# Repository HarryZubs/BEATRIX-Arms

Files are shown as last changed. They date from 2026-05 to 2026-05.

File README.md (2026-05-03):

This Repo contains all of the required software and hardware to create an Open-Source BEATRIX Robot Arm.

# Hardware 

printFiles contains all of the STL files that are required to be 3D printed for the full robot arm. All prints are required to be 30% infill PLA.
BOM contains all of the parts required to be purchased to complete the robot arm.
buildGuide contains a guide to the assembly of the arm.
schem contains an Altium Designer Schematic file defining the electrical connections for the full system.

# Software

Contains all of the software required to control the arm.

## WSL contains all of the ROS software

This was all ran inside WSL2 in an Ubuntu 20.04 envionment using ros-noetic.
Any ros-noetic build should be functional however Ubuntu 20.04 is reccommended. 
All essnetial packages are required: python3-rosdep python3-rosinstall python3-rosinstall-generator python3-wstool build-essential
Additionall ros-pinocchio is required: https://github.com/stack-of-tasks/pinocchio.git

To run the robot arm all of the ros nodes must be running simultaneously in a enviornment which is communcaiting over TCP with the GUI.

## WindowsGUI contains the GUI and communcation software

This is not unique to windows but was developed for a windows envionrment.
The required python packages are: pyserial and coppeliasim_zmqremoteapi_client.
Inside the code the COM port for the ardunio and the address for the communcation with the ROS software must be configured.

## Arduino contains the motor control software

This code must be flashed onto an ardunio. Any ardunio nano should function however it has only been tested with an ardunio nano rev2.
This requires the following package: Adafruit_PWMServoDriver

## Simulator contains the CoppeliaSim model

The file can be opened inside v4.10.0 and can then communciate and be controlled by the rest of the software.

# Testing contains all of the scripts used during development and testing of the arm

IMU Res contains the ardunio, python code and results of measuring the repeatability with the IMU.
Dynamic test evalutes the workspace of the arm under dyanmic conditions
Kinematic eval evlautes the kinematic workspace of the arm when compared to other humanoid kinematic chains
Motion eval evalutes the similarity betwwen motion of the robot arm and a human arm
Payload eval evaluates the reduction in workspace in loaded conditions
Pose gen generates random reachable poses
Rand pose is a ROS node that will communicate with the ROS software to instruct a move to a randomly reachable pose
Rand traj s a ROS node that will communicate with the ROS software to instruct randomly generated trajectory
Traj eval graphs the trajectory for a random pose

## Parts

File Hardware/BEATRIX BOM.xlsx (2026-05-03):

Ordered 04/03/26 by Harry | Stepper UK | Part | Quantity | Cost | Total | Link
 |  | J1/J2 Motor | 2 | £32.69 | £65.38 | https://www.stepperonline.co.uk/nema-17-stepper-motor-bipolar-l-48mm-w-gear-ratio-14-1-planetary-gearbox-17hs19-1684s-pg14.html
 |  | J3 Motor | 1 | £23.79 | £23.79 | https://www.stepperonline.co.uk/nema-17-stepper-motor-l-39mm-gear-ratio-10-1-mg-series-planetary-gearbox-17hs15-1584s-mg10.html
 |  | J4/J5/J6/J7 Motor | 1 | £22.67 | £22.67 | https://www.stepperonline.co.uk/5pcs-e-series-nema-17-bipolar-42ncm-59-49oz-in-1-5a-42x42x38mm-4-wires-w-1m-cable-connector-5-17he15-1504s.html
 |  | Delivery |  |  | £9.40
 |  | Total |  |  | £121.24
 | Simply Bearings | Part | Quantity | Cost | Total | Link
 |  | J1 / J3 Bearings | 4 | £5.98 | £23.92 | https://simplybearings.co.uk/shop/p2146031/ZEN-618082RS-Rubber-Sealed-Deep-Groove-Ball-Bearing-40x52x7mm-Allow-2-3-Days/product_info.html
 |  | J2/J4/J6 Bearings | 6 | £3.98 | £23.88 | https://simplybearings.co.uk/shop/p170503/161012RS-Budget-Rubber-Sealed-Deep-Groove-Ball-Bearing-12x30x8mm/product_info.html
 |  | J5 Bearings | 2 | £4.27 | £8.54 | https://simplybearings.co.uk/shop/p2146128/ZEN-619052RS-Rubber-Sealed-Deep-Groove-Ball-Bearing-25x42x9mm-Allow-2-3-Days/product_info.html
 |  | J1 / J3 Circlip | 2 | £3.75 | £7.50 | https://simplybearings.co.uk/shop/p82858/External-Circlip-for-40mm-Shaft-Diameter-Un-Sprung-Diameter-36.5mm/product_info.html
 |  | J5 Circlip | 1 | £3.27 | £3.27 | https://simplybearings.co.uk/shop/p82843/External-Circlip-for-25mm-Shaft-Diameter-Un-Sprung-Diameter-23.2mm/product_info.html
 |  | VAT |  |  | £13.42
 |  | Total |  |  | £80.53
 | RS | Part | Quantity | Cost | Total | Link
 |  | J2/J4/J6 Circlip | 1 | £2.60 | £2.60 | https://uk.rs-online.com/web/p/circlips/0289247
 |  | M3 Inserts | 1 | £9.29 | £9.29 | https://uk.rs-online.com/web/p/threaded-inserts/0278534
 |  | M3 Bolts | 1 | £6.23 | £6.23 | https://uk.rs-online.com/web/p/machine-screws/9141771
 |  | M6 Bolts | 1 | £11.16 | £11.16 | https://uk.rs-online.com/web/p/socket-screws/8229127
 |  | M6 Nuts | 1 | £5.25 | £5.25 | https://uk.rs-online.com/web/p/hex-nuts/0525919
 |  | VAT |  |  | £6.91
 |  | Total |  |  | £41.44
 |  | Total |  |  | £243.21
To be ordered by Uriel | Amazon | Part | Quantity | Cost | Total | Link
 |  | J2/J4/J6 Driven Pulley | 3 | £6.19 | £18.57 | https://www.amazon.co.uk/sourcing-map-Synchronous-Aluminum-Printer/dp/B0DNFCVW62
 |  | J2 Drive Pulley | 1 | £8.98 | £8.98 | https://www.amazon.co.uk/Super-Pulley-Aluminum-Timing-Printer/dp/B0CND54G7W?s=industrial
 |  | J4/J6 Drive Pulley | 1 | £8.98 | £8.98 | https://www.amazon.co.uk/Super-Pulley-Aluminum-Timing-Printer/dp/B0CND58QZJ?s=industrial
 |  | J2/J4/J6 Belt | 3 | £7.39 | £22.17 | https://www.amazon.co.uk/Closed-Loop-Timing-Synchronous-Printer-Accessories/dp/B0B2W9V3N6?s=industrial
 |  | J2/J4/J6 Idlier | 1 | £11.98 | £11.98 | https://www.amazon.co.uk/Super-Pulley-Aluminum-Timing-Printer/dp/B0F82V92D9?s=industrial
 |  | Delivery |  |  | £0.00
 |  | Total |  |  | £70.68
Ask technicians for | Pi Hut | Part | Quantity | Cost | Total | Link
 |  | Stepper Motor Driver | 7 | £3.50 | £24.50 | https://thepihut.com/products/l298n-motor-stepper-driver
 |  | Delivery |  |  | £3.50
 |  | Total |  |  | £28.00

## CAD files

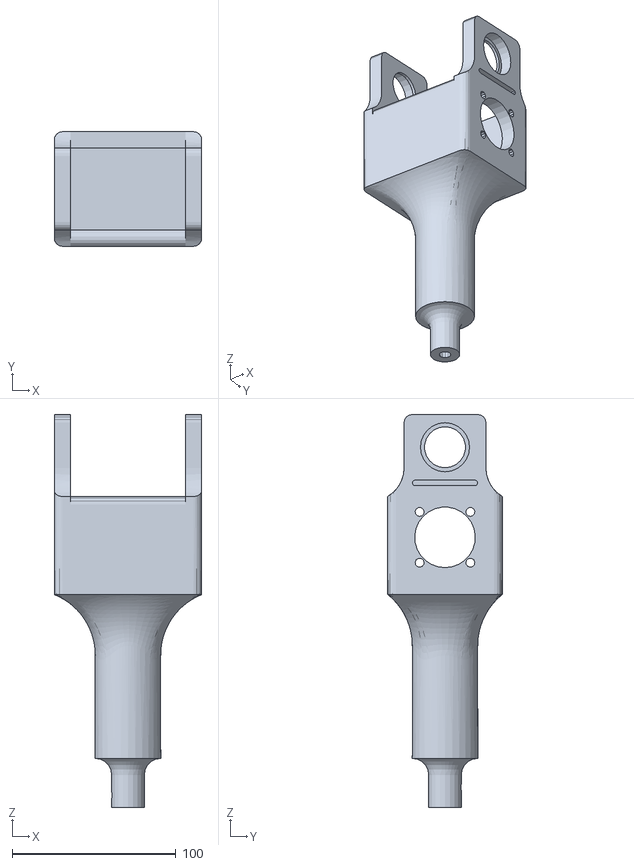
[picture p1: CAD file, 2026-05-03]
Hardware/PrintFiles/J1_Main.stl
90.0 x 70.0 x 240.0

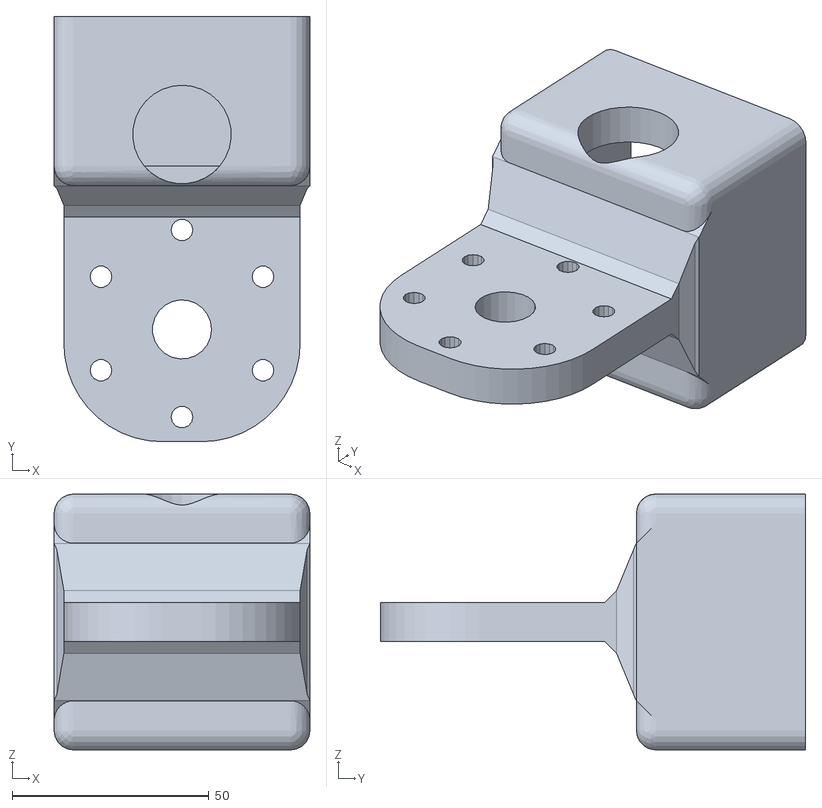
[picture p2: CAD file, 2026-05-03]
Hardware/PrintFiles/J4_Main.stl
65.0 x 108.0 x 65.0

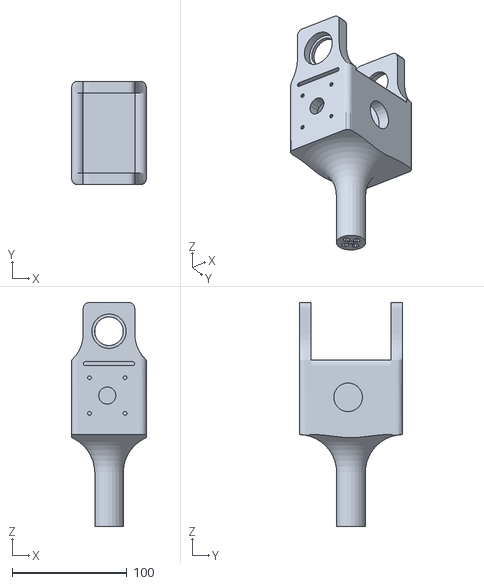
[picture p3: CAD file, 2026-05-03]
Hardware/PrintFiles/J5_Main.stl
65.0 x 90.0 x 195.0

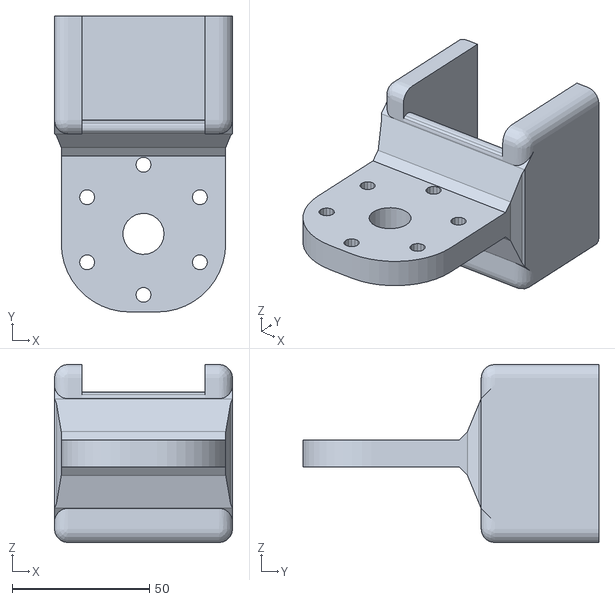
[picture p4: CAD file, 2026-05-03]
Hardware/PrintFiles/L2_main.stl
65.0 x 108.0 x 65.0

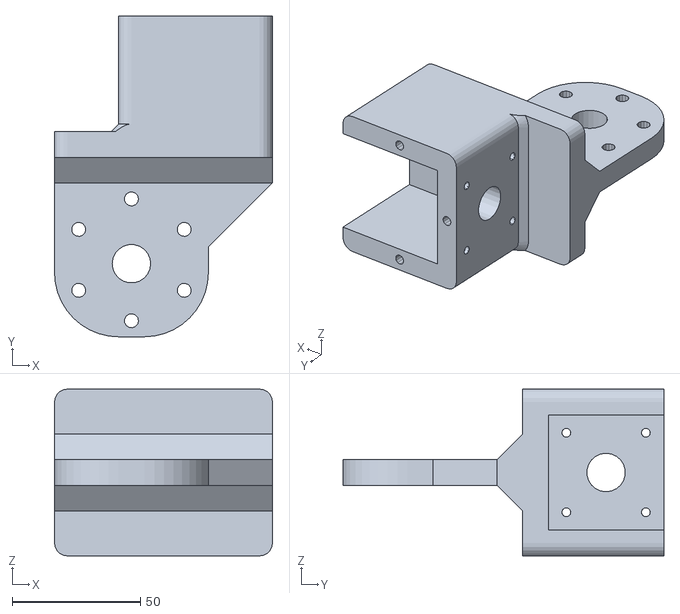
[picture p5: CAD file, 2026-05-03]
Hardware/PrintFiles/L6_main.stl
85.0 x 125.0 x 65.0

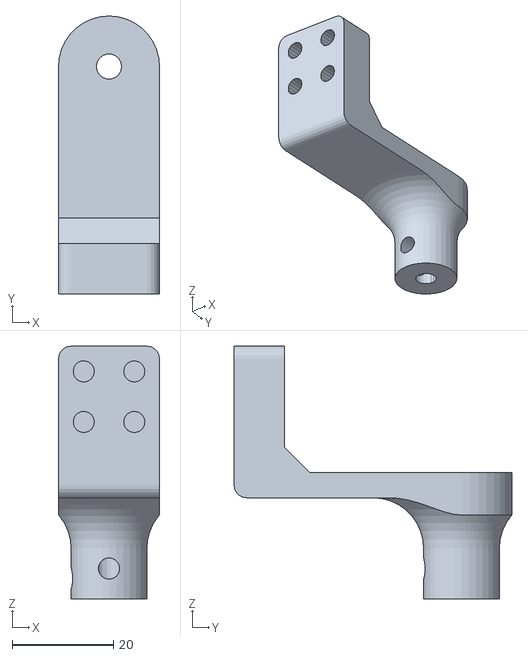
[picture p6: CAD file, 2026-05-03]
Hardware/PrintFiles/J7_Main.stl
20.0 x 55.0 x 50.0

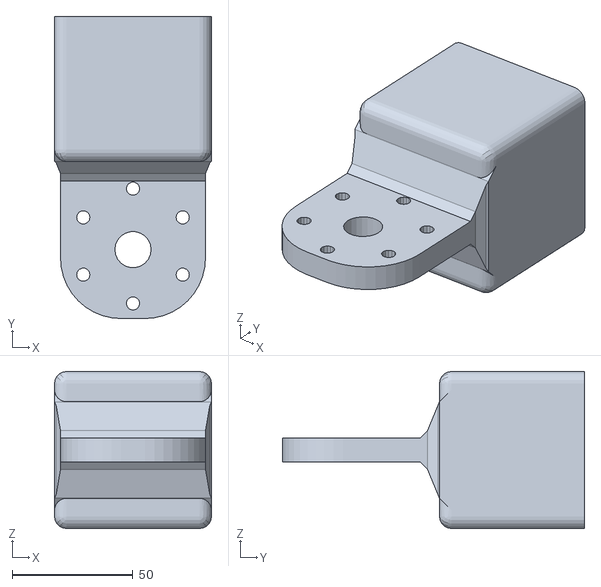
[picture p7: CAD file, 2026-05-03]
Hardware/PrintFiles/J2_Main.stl
65.0 x 125.0 x 65.0

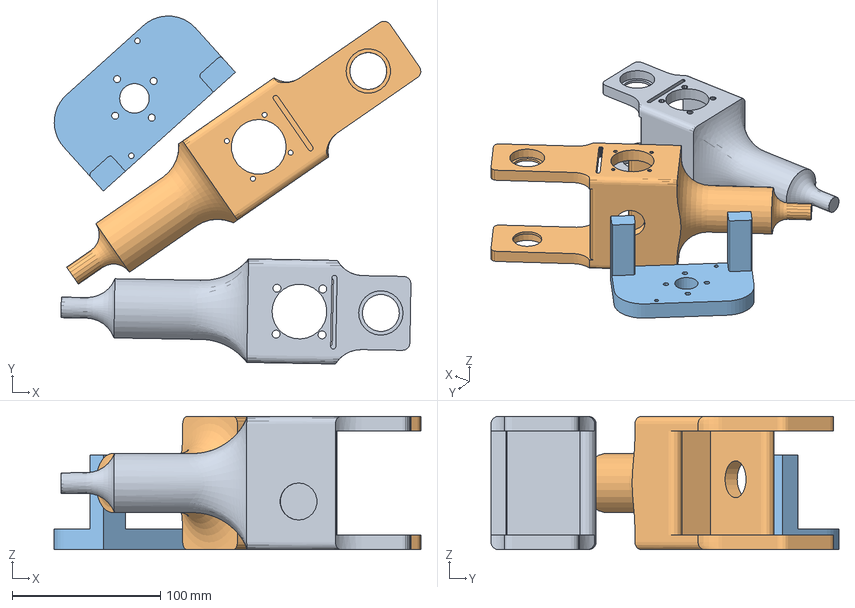
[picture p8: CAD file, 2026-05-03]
Hardware/PrintFiles/L1_Main.3mf
247.6 x 235.1 x 90.0 mm
L1_Main.stl
L3_Main.stl
L1_MountingPlate_3_Real.stl

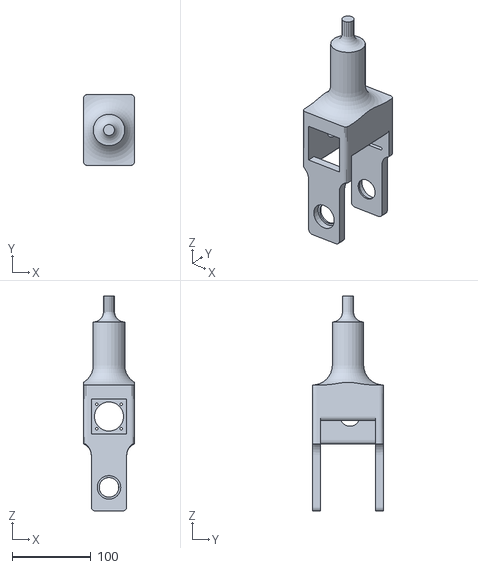
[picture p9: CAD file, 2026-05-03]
Hardware/PrintFiles/L3_Main.stl
65.0 x 90.0 x 273.0

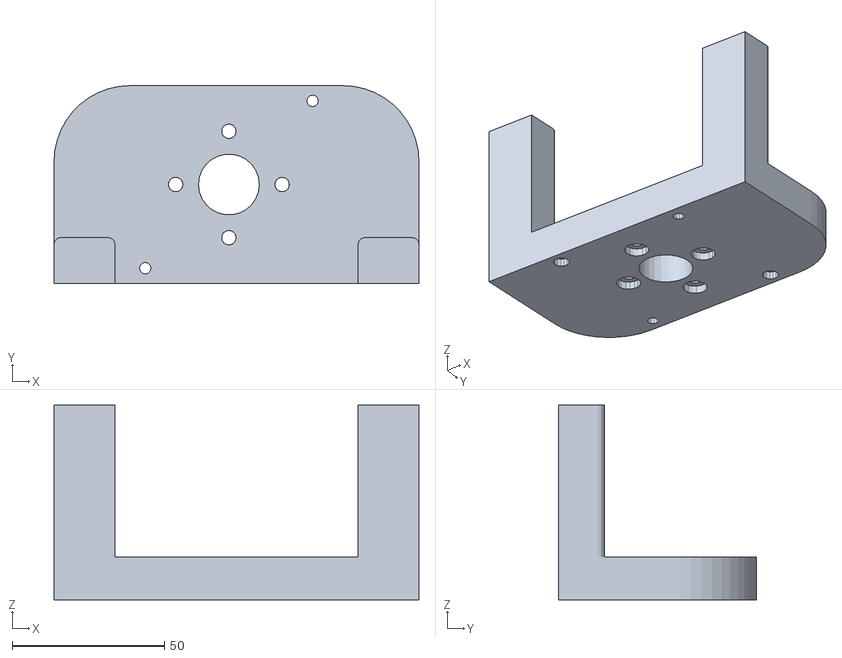
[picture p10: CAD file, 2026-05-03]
Hardware/PrintFiles/L1_MountingPlate_3_Real.stl
120.0 x 65.0 x 64.0

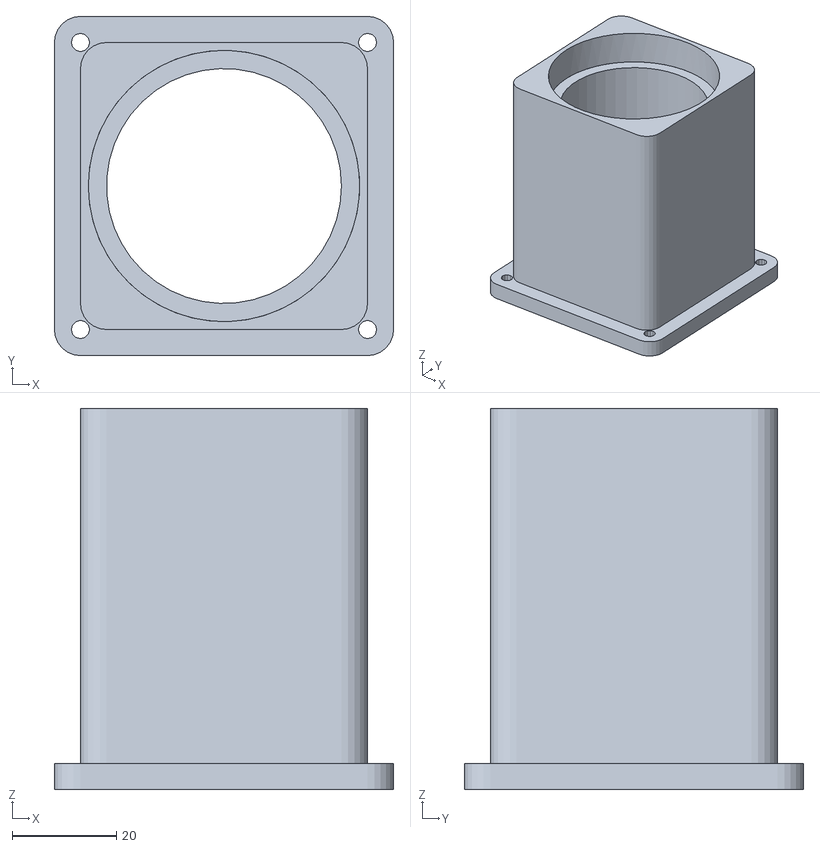
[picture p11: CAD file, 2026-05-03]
Hardware/PrintFiles/L1_BearingHousing.stl
65.0 x 65.0 x 73.0

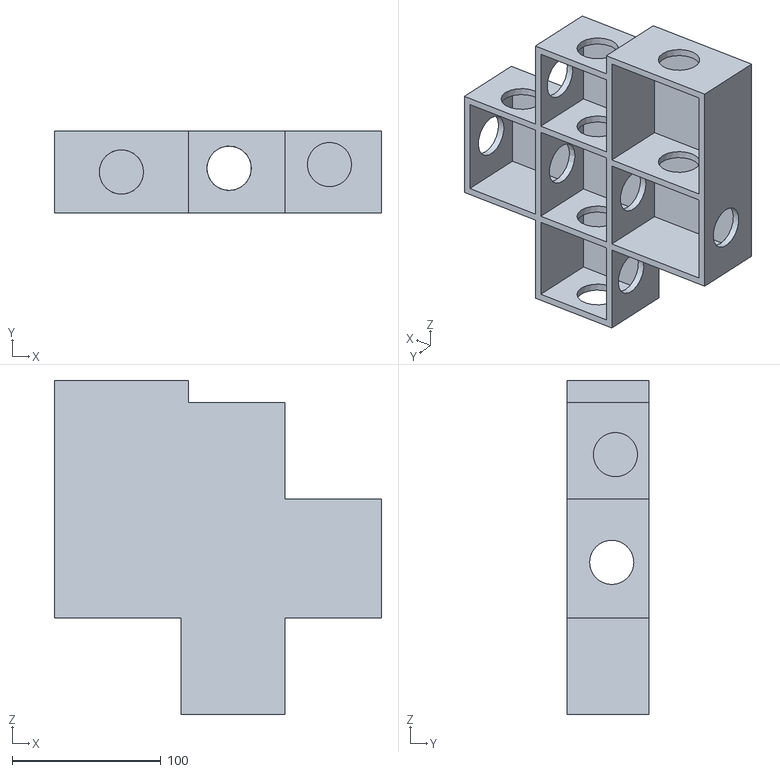
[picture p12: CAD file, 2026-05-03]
Hardware/PrintFiles/ElectronicsBox2.stl
220.0 x 55.0 x 225.0

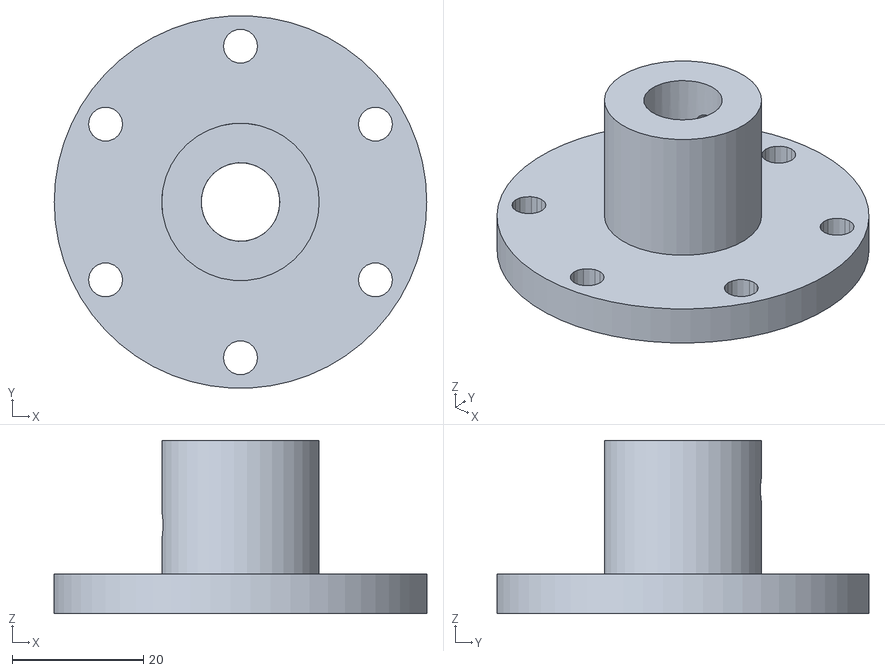
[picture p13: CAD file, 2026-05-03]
Hardware/PrintFiles/ClampingHub.stl
56.8 x 56.7 x 26.4

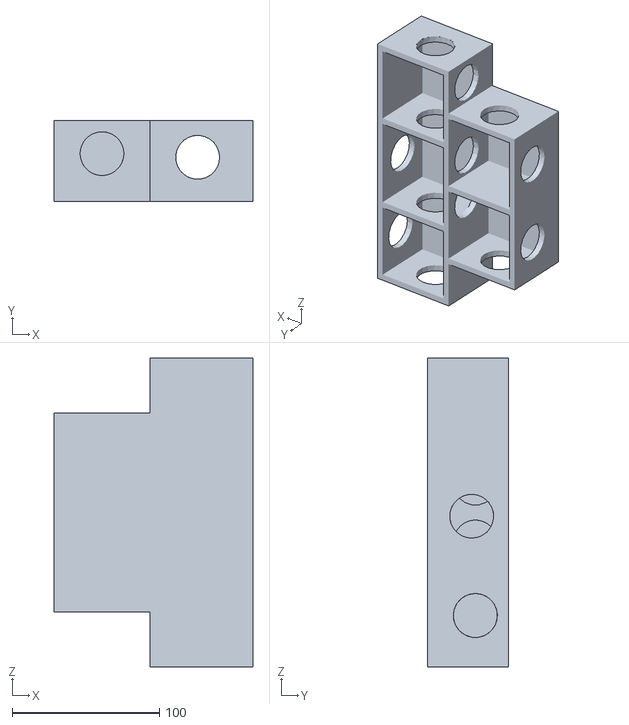
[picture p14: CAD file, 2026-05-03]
Hardware/PrintFiles/ElectronicsBox3.stl
135.0 x 55.0 x 210.0

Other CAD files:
Hardware/PrintFiles/L1_Chest_Interface.stl
Hardware/PrintFiles/ElectronicsBox.stl
Hardware/PrintFiles/J1_MountingPlate.stl
Hardware/PrintFiles/J4_Shaft.stl
Hardware/PrintFiles/J2_BearingHousing.stl
Hardware/PrintFiles/J2_Shaft.3mf
Hardware/PrintFiles/J2_Shaft.stl
Hardware/PrintFiles/J4_BearingHousing.stl
Hardware/PrintFiles/J4_MountingPlate.stl
Hardware/PrintFiles/J6_MountingPlate.stl
Hardware/PrintFiles/L1MotorMount.stl
Hardware/PrintFiles/L1_MountingPlate_3.stl
Hardware/PrintFiles/L2_Shaft.stl
Hardware/PrintFiles/L6_Shaft.stl

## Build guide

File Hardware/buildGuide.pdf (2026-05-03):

For the base and L2/L4/L6 the appropriate motor was attached to the mounting plate with M3 bolts. Threaded inserts were then hammered into both the mounting plate and link body and M3 bolts were used to attach the mounting plate to the body.

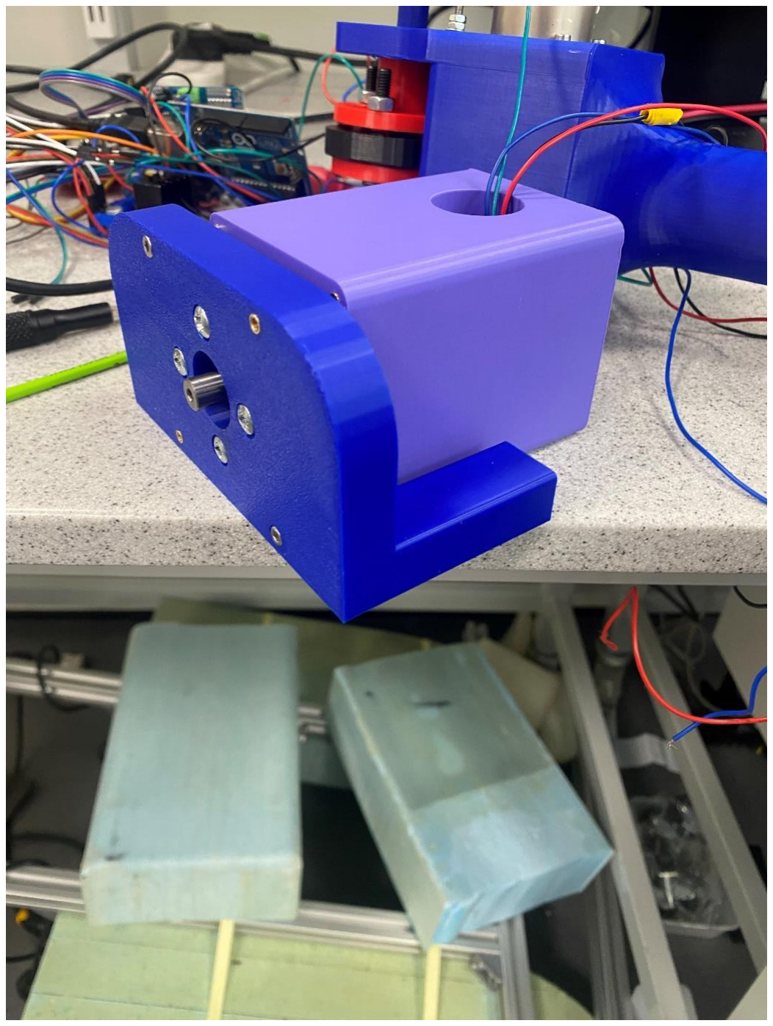
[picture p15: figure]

The bearings were then inserted into the appropriate bearing housing for each of the links.

The appropriate motor was mounted into L1/L3/L5 using the M3 bolts. For L1 and L3 this was a motor with a 14 reduction planetary gearbox while L5 had no gearbox. The same exact process was followed for all 3 links.

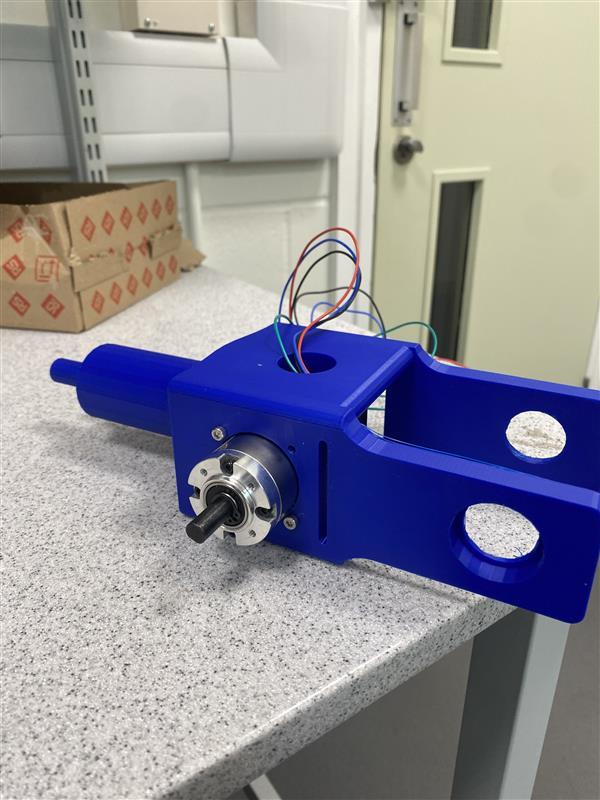
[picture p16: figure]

The coupling was then attached to the shaft of the link.

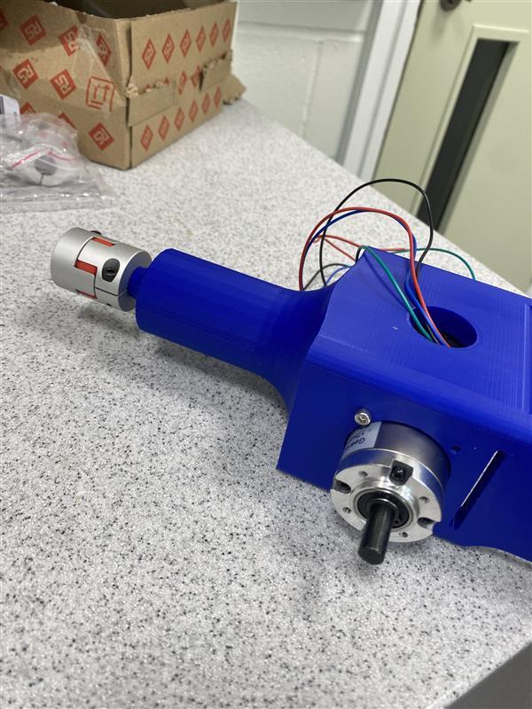
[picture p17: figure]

The bearings were then inserted with the use of a lubrication and a mallet.

The shaft was then inserted into one of the bearings again using lubrication and a mallet.

Threaded inserts were then hammered into all 6 of the clamping hubs.

The first clamping hub was mounted onto the shaft.

The fully assembled next link (L2/L4/L6) was then inserted onto the shaft.

The M6 bolts were placed inside the mounting holes of the clamping hub.

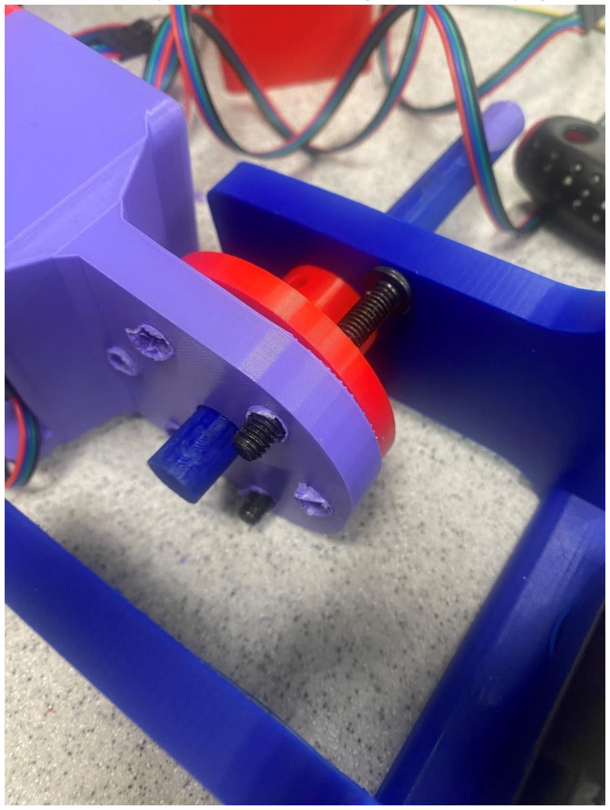
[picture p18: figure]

The second clamping hub was then inserted onto the other side of the shaft and M6 nuts were used to fasten everything securely.

The GT2 pulleys were mounted onto the shaft and motor with a 3:1 reduction ratio.

The threaded bars were inserted into the slot with idling pulleys mounted onto them. They were then adjusted to tension the belt.

The bearing housing for the base, L2/L4/L6 was then inserted into the next link.

The coupling was then attached to the motor shaft of the previous link.

Finally the bearing housing was slid into place and mounted to the mounting plate using M3 bolts.

L7 is then mounted onto the final motor, creating the full assembly of the arm.

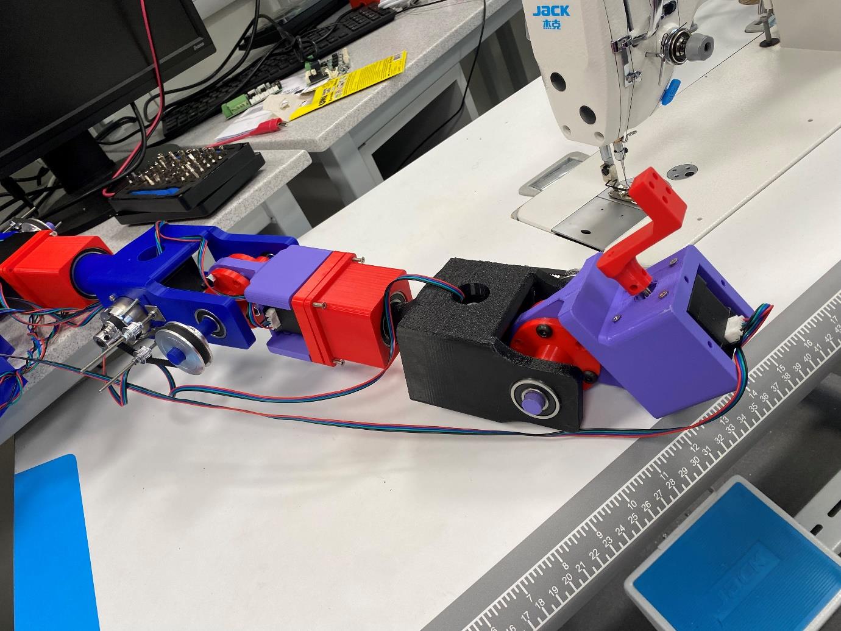
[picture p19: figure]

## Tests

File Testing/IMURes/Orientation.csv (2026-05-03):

BNO055 Orientation Sensor Test
X: 0.0000  Y: 0.0000  Z: 0.0000
X: 0.0000  Y: 0.0000  Z: 0.0000
X: 0.0000  Y: 0.0000  Z: 0.0000
X: 0.0000  Y: 0.0000  Z: 0.0000
X: 0.0000  Y: 0.0000  Z: 0.0000
X: 0.0000  Y: 0.0000  Z: 0.0000
X: 148.1250  Y: -9.7500  Z: -142.5625
X: 148.2500  Y: -9.7500  Z: -142.5625
X: 148.1875  Y: -9.6250  Z: -142.5000
X: 148.1875  Y: -9.6875  Z: -142.5000
X: 147.8125  Y: -10.2500  Z: -142.5000
X: 145.9375  Y: -11.0625  Z: -139.1875
X: 355.8125  Y: -12.2500  Z: -132.8750
X: 358.1875  Y: -15.8750  Z: -126.7500
X: 0.7500  Y: -21.8125  Z: -118.5000
X: 4.3750  Y: -29.5625  Z: -113.9375
X: 4.8750  Y: -38.0000  Z: -110.2500
X: 0.0625  Y: -44.2500  Z: -110.8750
X: 0.0625  Y: -45.7500  Z: -116.8750
X: 358.8125  Y: -45.1250  Z: -118.6875
X: 356.8750  Y: -44.1250  Z: -118.3750
X: 355.5625  Y: -43.3125  Z: -118.6875
X: 355.6250  Y: -43.5000  Z: -118.6250
X: 356.6875  Y: -44.0625  Z: -118.3750
X: 2.8125  Y: -43.7500  Z: -120.4375
X: 8.7500  Y: -38.7500  Z: -121.8750
X: 9.7500  Y: -29.0000  Z: -126.0000
X: 7.8750  Y: -18.9375  Z: -134.7500
X: 153.2500  Y: -6.1875  Z: -139.1875
X: 168.5000  Y: 11.5000  Z: -143.6875
X: 172.6250  Y: 14.7500  Z: -142.2500
X: 172.9375  Y: 14.1250  Z: -141.6875
X: 172.2500  Y: 13.4375  Z: -140.8750
X: 170.8750  Y: 11.2500  Z: -140.6250
X: 169.8125  Y: 9.6875  Z: -139.8750
X: 168.0625  Y: 7.9375  Z: -139.4375
X: 164.4375  Y: 3.5625  Z: -136.8750
X: 343.3750  Y: -0.7500  Z: -133.1250
X: 352.0625  Y: -5.6250  Z: -132.1250
X: 5.1875  Y: -17.3750  Z: -124.7500
X: 12.0000  Y: -26.5000  Z: -120.1250
X: 12.0000  Y: -36.9375  Z: -111.9375
X: 12.8125  Y: -46.1875  Z: -115.0625
X: 15.3125  Y: -49.2500  Z: -122.3125
X: 14.6250  Y: -49.3125  Z: -124.8750
X: 12.0625  Y: -48.3125  Z: -124.7500
X: 11.0625  Y: -47.5000  Z: -125.3125
X: 9.8125  Y: -47.1250  Z: -124.2500
X: 9.8750  Y: -46.8125  Z: -122.0000
X: 12.5625  Y: -43.7500  Z: -120.8125
X: 15.6875  Y: -37.3125  Z: -123.5000
X: 16.7500  Y: -27.9375  Z: -127.8750
X: 359.0000  Y: -11.6875  Z: -131.5000
X: 161.3750  Y: 3.2500  Z: -137.8125
X: 170.3125  Y: 12.0000  Z: -138.2500
X: 169.6250  Y: 9.1875  Z: -136.8750
X: 324.5000  Y: 8.5625  Z: -135.3750
X: 325.5625  Y: 8.2500  Z: -135.0000
X: 326.3750  Y: 7.7500  Z: -135.4375
X: 331.1875  Y: 5.2500  Z: -135.1875
X: 339.0625  Y: 1.4375  Z: -130.6250
X: 345.4375  Y: -2.2500  Z: -127.6250
X: 356.6250  Y: -10.2500  Z: -121.5000
X: 7.1250  Y: -20.0000  Z: -117.5000
X: 19.9375  Y: -31.5000  Z: -119.6875
X: 29.3125  Y: -41.4375  Z: -124.8750
X: 33.9375  Y: -46.0000  Z: -130.6250
X: 33.8750  Y: -46.5625  Z: -132.1250
X: 32.1875  Y: -45.8125  Z: -132.3125
X: 31.4375  Y: -45.6875  Z: -132.0625
X: 308.8125  Y: -45.3750  Z: -130.8750
X: 304.8125  Y: -42.6875  Z: -126.8125
X: 302.1875  Y: -37.3750  Z: -125.0625
X: 303.4375  Y: -29.1875  Z: -131.7500
X: 293.3125  Y: -17.5000  Z: -137.7500
X: 74.2500  Y: -6.2500  Z: -139.0625
X: 84.1250  Y: 6.2500  Z: -141.9375
X: 90.4375  Y: 13.8125  Z: -142.4375
X: 89.7500  Y: 13.0000  Z: -141.6875
X: 89.6875  Y: 12.5625  Z: -141.1875
X: 89.5625  Y: 11.8125  Z: -141.3125
X: 88.0000  Y: 10.5625  Z: -141.1875
X: 85.1875  Y: 7.1250  Z: -140.5625
X: 81.1875  Y: 1.9375  Z: -137.1250
X: 270.6250  Y: -5.6250  Z: -132.3750
X: 285.0000  Y: -13.8750  Z: -130.6875
X: 297.8750  Y: -23.0000  Z: -129.0000
X: 307.6875  Y: -32.9375  Z: -126.3750
X: 316.3750  Y: -42.3125  Z: -128.2500
X: 316.0625  Y: -49.0000  Z: -131.9375
X: 310.8750  Y: -49.9375  Z: -134.1875
X: 309.8125  Y: -49.5000  Z: -134.5000
X: 307.1250  Y: -47.9375  Z: -134.5000
X: 305.9375  Y: -47.5625  Z: -134.0625
X: 304.6875  Y: -47.0000  Z: -132.9375
X: 308.8125  Y: -45.8125  Z: -133.7500
X: 312.6875  Y: -42.1875  Z: -134.5625
X: 313.2500  Y: -34.1875  Z: -137.5000
X: 310.6875  Y: -25.6250  Z: -141.5625
X: 65.8750  Y: -14.7500  Z: -145.2500
X: 77.6875  Y: -1.5625  Z: -147.6875
X: 87.3750  Y: 10.0625  Z: -148.4375
X: 90.1875  Y: 11.4375  Z: -147.5625
X: 90.3125  Y: 10.8125  Z: -146.8750
X: 90.1250  Y: 9.8750  Z: -146.3125
X: 89.2500  Y: 8.5000  Z: -146.6875
X: 86.5000  Y: 5.5000  Z: -145.3750
X: 84.0625  Y: 2.1875  Z: -140.3125
X: 79.3125  Y: -3.3125  Z: -135.8750
X: 279.5000  Y: -9.8750  Z: -132.4375
X: 287.8125  Y: -17.1875  Z: -128.0625
X: 293.3125  Y: -25.5000  Z: -122.2500
X: 300.6875  Y: -37.0625  Z: -120.3125
X: 295.3125  Y: -46.8750  Z: -115.1875
X: 295.8125  Y: -50.1875  Z: -119.7500
X: 295.5000  Y: -49.5625  Z: -122.9375
X: 293.4375  Y: -48.0000  Z: -124.1875
X: 291.8750  Y: -47.2500  Z: -124.3125
X: 292.0000  Y: -46.7500  Z: -123.3750
X: 292.7500  Y: -44.8125  Z: -121.0000
X: 299.6250  Y: -40.1250  Z: -124.5000
X: 300.6250  Y: -32.8750  Z: -128.4375
X: 298.6250  Y: -23.7500  Z: -135.0625
X: 64.6875  Y: -16.0625  Z: -143.5625
X: 73.5625  Y: -7.7500  Z: -150.2500
X: 83.0000  Y: 4.5000  Z: -153.3750
X: 87.6875  Y: 9.9375  Z: -152.1875
X: 87.0000  Y: 8.0000  Z: -151.4375
X: 86.6875  Y: 7.0625  Z: -150.5000
X: 85.8750  Y: 6.4375  Z: -150.6875
X: 85.1875  Y: 5.2500  Z: -149.4375
X: 82.7500  Y: 1.8125  Z: -144.5625
X: 78.0000  Y: -4.0625  Z: -137.0000
X: 278.2500  Y: -9.6250  Z: -131.7500
X: 283.3125  Y: -14.4375  Z: -126.0625
X: 291.6250  Y: -23.6250  Z: -120.3750
X: 295.5625  Y: -33.1875  Z: -115.1250
X: 297.6875  Y: -43.4375  Z: -112.9375
X: 291.0625  Y: -51.1250  Z: -115.2500
X: 292.8125  Y: -51.4375  Z: -122.8750
X: 290.7500  Y: -50.5625  Z: -123.0625
X: 288.8750  Y: -49.1250  Z: -123.5000
X: 287.9375  Y: -49.0000  Z: -122.3125
X: 287.0000  Y: -48.5000  Z: -118.6250
X: 288.0625  Y: -46.8750  Z: -114.0000
X: 291.8750  Y: -41.1250  Z: -114.5000
X: 293.2500  Y: -33.5000  Z: -118.2500
X: 287.7500  Y: -24.0625  Z: -121.7500
X: 282.6875  Y: -14.3750  Z: -132.3125
X: 71.9375  Y: -6.4375  Z: -140.6875
X: 78.8125  Y: 1.6875  Z: -145.5000
X: 85.6875  Y: 10.6250  Z: -146.2500
X: 87.1875  Y: 11.0000  Z: -145.0625
X: 87.2500  Y: 10.3750  Z: -144.4375
X: 87.6875  Y: 9.9375  Z: -144.1875
X: 86.0000  Y: 7.7500  Z: -144.0625
X: 83.1250  Y: 3.5625  Z: -137.0625
X: 263.8750  Y: -2.3750  Z: -130.5000
X: 275.1250  Y: -10.1250  Z: -123.8750
X: 283.6250  Y: -19.1250  Z: -117.8125
X: 288.3125  Y: -27.5625  Z: -112.7500
X: 290.8125  Y: -35.6875  Z: -110.6250
X: 291.9375  Y: -44.1875  Z: -112.6250
X: 290.5000  Y: -49.7500  Z: -117.7500
X: 291.7500  Y: -50.3750  Z: -122.9375
X: 290.2500  Y: -49.6250  Z: -123.5000
X: 288.4375  Y: -48.6250  Z: -123.8125
X: 287.4375  Y: -48.3125  Z: -123.8125
X: 287.5000  Y: -48.3125  Z: -122.4375
X: 296.5000  Y: -47.2500  Z: -124.9375
X: 300.9375  Y: -42.0625  Z: -126.1875
X: 299.8125  Y: -33.8125  Z: -128.2500
X: 295.0625  Y: -24.7500  Z: -131.8750
X: 63.5625  Y: -14.1250  Z: -138.4375
X: 72.5625  Y: -5.1875  Z: -143.4375
X: 79.1250  Y: 3.3125  Z: -148.3125
X: 82.0000  Y: 6.0625  Z: -149.6250
X: 82.0000  Y: 5.4375  Z: -150.4375
X: 82.9375  Y: 5.1875  Z: -149.5000
X: 82.8125  Y: 4.9375  Z: -149.3750
X: 81.0000  Y: 3.1875  Z: -147.8125
X: 78.1875  Y: 0.0000  Z: -140.8750
X: 266.5000  Y: -4.2500  Z: -132.6875
X: 278.4375  Y: -12.4375  Z: -127.7500
X: 288.8750  Y: -23.1875  Z: -123.7500
X: 293.1875  Y: -31.1250  Z: -118.9375
X: 292.0625  Y: -41.4375  Z: -112.3125
X: 290.5625  Y: -49.8125  Z: -112.1875
X: 291.6250  Y: -54.1250  Z: -119.9375
X: 290.2500  Y: -52.5625  Z: -125.7500
X: 287.3125  Y: -50.6250  Z: -126.5625
X: 286.2500  Y: -50.4375  Z: -126.0625
X: 286.6875  Y: -50.6875  Z: -125.2500
X: 288.9375  Y: -50.5000  Z: -122.8125
X: 291.0625  Y: -48.5000  Z: -120.1875
X: 295.5000  Y: -44.0625  Z: -120.6875
X: 296.5000  Y: -36.0000  Z: -122.8125
X: 294.6250  Y: -27.0625  Z: -128.1875
X: 287.7500  Y: -17.2500  Z: -134.3750
X: 74.3125  Y: -3.8125  Z: -136.5625
X: 236.3750  Y: 10.9375  Z: -134.6250
X: 232.3750  Y: 14.1875  Z: -131.3750
X: 238.8125  Y: 11.1250  Z: -132.2500
X: 241.8750  Y: 10.0625  Z: -131.7500
X: 248.0625  Y: 7.0000  Z: -132.0000
X: 257.8125  Y: 1.8750  Z: -132.4375
X: 267.7500  Y: -3.3125  Z: -131.7500
X: 269.9375  Y: -4.4375  Z: -127.1875
X: 275.9375  Y: -9.1250  Z: -120.7500
X: 289.4375  Y: -19.6250  Z: -119.7500
X: 298.7500  Y: -30.8125  Z: -117.3750
X: 303.0000  Y: -39.2500  Z: -115.2500
X: 301.6875  Y: -47.7500  Z: -112.4375
X: 302.0000  Y: -54.6250  Z: -114.6875
X: 297.2500  Y: -59.3750  Z: -116.8750
X: 296.3125  Y: -60.1250  Z: -121.2500
X: 294.3750  Y: -59.1875  Z: -121.4375
X: 291.7500  Y: -57.9375  Z: -121.6250
X: 290.6875  Y: -57.3750  Z: -120.1250
X: 293.3125  Y: -55.9375  Z: -118.8750
X: 299.1250  Y: -52.5000  Z: -120.6875
X: 306.7500  Y: -45.9375  Z: -125.0000
X: 302.5625  Y: -37.4375  Z: -124.5000
X: 295.2500  Y: -26.2500  Z: -128.0625
X: 280.3125  Y: -12.6250  Z: -135.0625
X: 76.1875  Y: 0.3750  Z: -137.1250
X: 78.5000  Y: 2.4375  Z: -137.5000
X: 77.5000  Y: 0.9375  Z: -137.7500
X: 77.5000  Y: 0.4375  Z: -137.2500
X: 77.5000  Y: 0.3750  Z: -136.9375
X: 76.6250  Y: -0.8750  Z: -135.6875
X: 268.3750  Y: -6.0000  Z: -130.6250
X: 279.8125  Y: -14.1250  Z: -125.3750
X: 287.6875  Y: -24.3125  Z: -118.5000
X: 290.5625  Y: -35.8125  Z: -109.6875
X: 292.1875  Y: -45.8750  Z: -105.6250
X: 294.8750  Y: -54.0625  Z: -109.2500
X: 291.6875  Y: -58.1875  Z: -116.0625
X: 290.5000  Y: -57.6875  Z: -122.5000
X: 288.1250  Y: -56.0000  Z: -123.4375
X: 286.1875  Y: -55.3125  Z: -123.2500
X: 285.7500  Y: -55.3125  Z: -123.0000
X: 285.5625  Y: -55.7500  Z: -120.5000
X: 285.3750  Y: -55.8125  Z: -113.0000
X: 283.6250  Y: -50.7500  Z: -106.2500
X: 283.6875  Y: -44.0000  Z: -104.9375
X: 282.0000  Y: -37.6250  Z: -103.0000
X: 278.1875  Y: -28.8125  Z: -104.0000
X: 274.5625  Y: -19.3750  Z: -111.2500
X: 266.8750  Y: -10.3125  Z: -120.2500
X: 258.0625  Y: -3.0000  Z: -130.4375
X: 248.3125  Y: 2.5000  Z: -134.0625
X: 244.3750  Y: 4.6875  Z: -134.2500
X: 245.5000  Y: 4.3125  Z: -134.0625
X: 246.4375  Y: 4.0000  Z: -133.9375
X: 248.9375  Y: 3.7500  Z: -133.6875
X: 255.8750  Y: 1.3125  Z: -131.3750
X: 269.3125  Y: -5.5625  Z: -124.8750
X: 280.4375  Y: -15.2500  Z: -117.6250
X: 287.0625  Y: -24.8125  Z: -111.7500
X: 292.6250  Y: -34.6875  Z: -108.6250
X: 293.6250  Y: -44.5000  Z: -106.6250
X: 288.6875  Y: -52.7500  Z: -105.0625
X: 285.8125  Y: -58.0625  Z: -112.5000
X: 285.1875  Y: -56.9375  Z: -119.8125
X: 280.7500  Y: -54.2500  Z: -121.1875
X: 279.3750  Y: -53.8125  Z: -120.7500
X: 279.2500  Y: -54.2500  Z: -119.8125
X: 279.2500  Y: -54.3750  Z: -116.1250
X: 281.1250  Y: -55.1875  Z: -106.8125
X: 283.3750  Y: -52.3750  Z: -99.3750
X: 284.3125  Y: -45.6250  Z: -95.7500
X: 278.2500  Y: -35.1250  Z: -92.0625
X: 271.0000  Y: -22.1875  Z: -92.7500
X: 264.7500  Y: -11.0000  Z: -99.5625
X: 255.8750  Y: -1.0000  Z: -108.3750
X: 249.2500  Y: 4.1250  Z: -118.5625
X: 249.6250  Y: 3.7500  Z: -120.2500
X: 250.8125  Y: 3.3125  Z: -120.3125
X: 252.8125  Y: 2.3125  Z: -120.3750
X: 253.5625  Y: 1.8750  Z: -119.6875
X: 255.6250  Y: 0.9375  Z: -117.5000
X: 257.5625  Y: 0.1875  Z: -113.5625
X: 261.4375  Y: -2.0625  Z: -105.0625
X: 267.2500  Y: -9.0000  Z: -96.9375
X: 276.9375  Y: -22.2500  Z: -93.3750
X: 284.3750  Y: -35.4375  Z: -93.2500
X: 285.6250  Y: -45.8750  Z: -92.2500
X: 283.2500  Y: -54.2500  Z: -95.4375
X: 285.6250  Y: -59.3750  Z: -109.3750
X: 285.5625  Y: -57.3750  Z: -123.8125
X: 283.4375  Y: -54.1875  Z: -130.8125
X: 281.3125  Y: -53.9375  Z: -131.5000
X: 280.8125  Y: -54.6875  Z: -129.8750
X: 283.5000  Y: -56.0625  Z: -127.0625
X: 294.1875  Y: -57.2500  Z: -123.3750
X: 304.0000  Y: -55.8125  Z: -117.2500
X: 306.7500  Y: -50.3750  Z: -113.9375
X: 307.2500  Y: -41.4375  Z: -117.2500
X: 302.9375  Y: -32.1250  Z: -120.3125
X: 294.1250  Y: -21.3125  Z: -124.8750
X: 274.9375  Y: -8.5000  Z: -128.7500
X: 268.2500  Y: -4.6250  Z: -131.7500
X: 269.0625  Y: -4.8750  Z: -132.3750
X: 270.0000  Y: -5.0625  Z: -132.7500
X: 271.1875  Y: -5.2500  Z: -133.6875
X: 272.6250  Y: -6.0625  Z: -132.5000
X: 275.9375  Y: -8.6250  Z: -127.1875
X: 280.6875  Y: -13.7500  Z: -118.5000
X: 286.0625  Y: -22.0625  Z: -110.1250
X: 292.3125  Y: -31.9375  Z: -106.1875
X: 297.7500  Y: -42.5625  Z: -106.3125
X: 303.1250  Y: -50.2500  Z: -112.3750
X: 303.8750  Y: -55.1250  Z: -122.6250
X: 303.0000  Y: -57.0000  Z: -129.7500
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

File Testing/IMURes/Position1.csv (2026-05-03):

BNO055 Orientation Sensor Test
X: 0.0000  Y: 0.0000  Z: 0.0000
X: 0.0000  Y: 0.0000  Z: 0.0000
X: 0.0000  Y: 0.0000  Z: 0.0000
X: 0.0000  Y: 0.0000  Z: 0.0000
X: 0.0000  Y: 0.0000  Z: 0.0000
X: 0.0000  Y: 0.0000  Z: 0.0000
X: 359.9375  Y: 62.8125  Z: -64.6250
X: 359.9375  Y: 62.8125  Z: -64.6250
X: 359.9375  Y: 62.8125  Z: -64.6250
X: 359.9375  Y: 62.8125  Z: -64.6250
X: 359.9375  Y: 62.8125  Z: -64.6250
X: 359.9375  Y: 62.8125  Z: -64.6250
X: 359.9375  Y: 62.8125  Z: -64.6250
X: 359.9375  Y: 62.8125  Z: -64.6250
X: 359.9375  Y: 62.8125  Z: -64.6250
X: 359.9375  Y: 62.8125  Z: -64.6250
X: 359.9375  Y: 62.8125  Z: -64.6250
X: 359.8750  Y: 62.8125  Z: -64.5000
X: 359.9375  Y: 62.8750  Z: -64.6250
X: 1.0000  Y: 61.5625  Z: -60.4375
X: 4.5625  Y: 59.5625  Z: -50.5000
X: 8.9375  Y: 56.6250  Z: -35.1250
X: 13.6250  Y: 54.4375  Z: -11.3750
X: 15.0000  Y: 51.6250  Z: 7.8125
X: 16.6250  Y: 48.8125  Z: 32.1875
X: 17.3125  Y: 44.3125  Z: 54.0000
X: 18.3125  Y: 43.1250  Z: 62.3125
X: 19.3750  Y: 44.5625  Z: 62.5625
X: 19.2500  Y: 45.3125  Z: 62.8125
X: 19.4375  Y: 45.7500  Z: 62.6875
X: 19.5000  Y: 45.9375  Z: 62.7500
X: 19.6250  Y: 46.3125  Z: 62.9375
X: 19.7500  Y: 46.6250  Z: 63.0000
X: 19.8750  Y: 46.8750  Z: 62.8750
X: 19.9375  Y: 47.3125  Z: 63.1875
X: 20.1250  Y: 48.3750  Z: 63.3750
X: 20.8125  Y: 51.0000  Z: 55.6875
X: 22.5625  Y: 54.0000  Z: 46.0625
X: 24.1875  Y: 57.8125  Z: 38.7500
X: 25.6250  Y: 61.9375  Z: 29.6875
X: 27.2500  Y: 66.3750  Z: 15.9375
X: 28.3750  Y: 70.1875  Z: 0.4375
X: 25.0000  Y: 71.4375  Z: -19.1250
X: 18.9375  Y: 71.5625  Z: -38.7500
X: 12.4375  Y: 71.6875  Z: -52.1250
X: 7.4375  Y: 71.2500  Z: -57.5000
X: 5.1875  Y: 70.7500  Z: -59.2500
X: 5.1250  Y: 70.5625  Z: -59.0000
X: 5.4375  Y: 70.2500  Z: -58.6250
X: 5.5000  Y: 69.8750  Z: -57.0000
X: 5.8125  Y: 69.0000  Z: -54.9375
X: 6.1875  Y: 68.8125  Z: -53.4375
X: 6.1875  Y: 68.1250  Z: -52.7500
X: 6.0625  Y: 67.8125  Z: -49.8125
X: 6.8750  Y: 66.2500  Z: -44.1875
X: 14.0625  Y: 64.5625  Z: -23.1250
X: 17.0625  Y: 62.6250  Z: 8.5000
X: 15.5000  Y: 56.6250  Z: 33.9375
X: 14.3125  Y: 49.1250  Z: 56.6875
X: 12.6875  Y: 42.5625  Z: 70.1875
X: 12.7500  Y: 39.6250  Z: 76.6250
X: 13.1875  Y: 37.8750  Z: 83.3125
X: 14.8125  Y: 39.0000  Z: 83.5000
X: 15.3125  Y: 40.5625  Z: 83.9375
X: 15.1875  Y: 41.5000  Z: 84.6250
X: 15.6250  Y: 42.4375  Z: 84.1250
X: 16.3750  Y: 43.8750  Z: 81.2500
X: 17.2500  Y: 45.3125  Z: 78.1250
X: 17.5625  Y: 45.9375  Z: 76.6250
X: 17.6250  Y: 46.5625  Z: 76.8750
X: 18.4375  Y: 49.5000  Z: 72.9375
X: 19.5000  Y: 54.2500  Z: 66.4375
X: 20.9375  Y: 59.2500  Z: 62.4375
X: 22.1875  Y: 64.7500  Z: 55.8125
X: 23.8750  Y: 72.0000  Z: 46.6250
X: 23.5625  Y: 77.7500  Z: 29.6875
X: 22.0625  Y: 81.0000  Z: 2.0625
X: 18.0000  Y: 81.3125  Z: -29.3125
X: 14.2500  Y: 81.7500  Z: -47.5625
X: 12.4375  Y: 81.9375  Z: -56.0000
X: 12.1875  Y: 81.7500  Z: -55.0625
X: 12.5000  Y: 81.1875  Z: -51.6250
X: 12.8750  Y: 80.3750  Z: -49.3125
X: 13.3125  Y: 79.5000  Z: -47.6250
X: 13.7500  Y: 78.8750  Z: -47.8750
X: 13.5000  Y: 78.8750  Z: -46.2500
X: 14.3125  Y: 78.9375  Z: -44.8750
X: 14.3125  Y: 78.5625  Z: -39.1875
X: 14.0625  Y: 76.8125  Z: -27.6875
X: 14.6875  Y: 74.3125  Z: -10.1875
X: 14.0625  Y: 70.1250  Z: 17.3125
X: 14.4375  Y: 63.8750  Z: 42.5000
X: 13.0000  Y: 56.9375  Z: 61.3125
X: 11.7500  Y: 49.5000  Z: 77.8125
X: 11.0625  Y: 43.0625  Z: 89.8750
X: 10.1875  Y: 40.1875  Z: 94.1250
X: 10.6250  Y: 39.6875  Z: 95.7500
X: 11.4375  Y: 40.4375  Z: 95.6875
X: 11.3750  Y: 40.8125  Z: 95.8750
X: 11.4375  Y: 41.1875  Z: 96.0000
X: 11.7500  Y: 41.6250  Z: 95.3125
X: 12.0625  Y: 42.2500  Z: 94.7500
X: 11.9375  Y: 43.4375  Z: 94.5625
X: 12.4375  Y: 47.8125  Z: 90.9375
X: 15.0000  Y: 53.6250  Z: 86.1875
X: 18.7500  Y: 61.3750  Z: 79.5625
X: 22.0000  Y: 68.2500  Z: 73.8750
X: 24.8750  Y: 74.8750  Z: 66.1875
X: 218.6875  Y: 79.2500  Z: 51.9375
X: 215.1250  Y: 82.3750  Z: 24.9375
X: 209.8750  Y: 84.0625  Z: 0.0625
X: 205.6250  Y: 85.1250  Z: -1.3750
X: 204.1250  Y: 85.8125  Z: -1.5000
X: 204.4375  Y: 85.4375  Z: -1.8125
X: 205.0625  Y: 84.6875  Z: -2.2500
X: 205.2500  Y: 84.2500  Z: -2.3750
X: 205.3750  Y: 83.8750  Z: -2.4375
X: 205.6250  Y: 83.1250  Z: -2.4375
X: 206.4375  Y: 82.1250  Z: -16.8750
X: 205.7500  Y: 80.9375  Z: -12.6875
X: 205.5000  Y: 79.6250  Z: -8.8125
X: 205.7500  Y: 77.8750  Z: -0.5625
X: 205.3125  Y: 74.5625  Z: 6.3750
X: 203.9375  Y: 69.3750  Z: 14.5000
X: 202.5000  Y: 64.2500  Z: 23.1250
X: 200.6250  Y: 59.1250  Z: 34.0000
X: 199.2500  Y: 53.0000  Z: 50.5625
X: 199.3750  Y: 47.5000  Z: 64.8125
X: 199.5000  Y: 42.5000  Z: 75.2500
X: 200.4375  Y: 39.0000  Z: 82.0625
X: 201.2500  Y: 39.0625  Z: 83.0625
X: 201.5000  Y: 39.6250  Z: 83.1250
X: 201.5625  Y: 40.2500  Z: 83.1875
X: 201.9375  Y: 40.6875  Z: 82.6250
X: 202.3125  Y: 40.9375  Z: 82.2500
X: 202.6250  Y: 41.4375  Z: 81.3750
X: 202.6250  Y: 42.0000  Z: 81.2500
X: 202.3125  Y: 42.4375  Z: 81.8125
X: 202.0000  Y: 43.2500  Z: 82.2500
X: 202.5000  Y: 45.8750  Z: 79.3750
X: 203.2500  Y: 49.6875  Z: 73.0625
X: 204.7500  Y: 55.4375  Z: 68.8125
X: 206.3125  Y: 62.4375  Z: 65.9375
X: 207.3125  Y: 69.1250  Z: 56.3125
X: 206.5000  Y: 74.8125  Z: 37.3125
X: 203.6875  Y: 78.3750  Z: 14.6250
X: 199.3750  Y: 81.0625  Z: -4.0625
X: 195.7500  Y: 82.7500  Z: -12.5000
X: 195.3750  Y: 84.4375  Z: -1.5000
X: 195.5625  Y: 84.5000  Z: -1.7500
X: 196.3125  Y: 84.1250  Z: -2.0625
X: 196.6250  Y: 83.7500  Z: -2.1875
X: 197.1250  Y: 83.3125  Z: -2.3125
X: 197.5000  Y: 82.8125  Z: -20.5625
X: 197.6250  Y: 82.5625  Z: -20.8125
X: 198.1250  Y: 81.6250  Z: -18.7500
X: 199.2500  Y: 79.7500  Z: -12.6250
X: 199.3750  Y: 76.6250  Z: -6.2500
X: 199.1875  Y: 71.5625  Z: 0.6875
X: 198.3750  Y: 65.8125  Z: 9.5000
X: 198.5000  Y: 60.6875  Z: 24.4375
X: 198.7500  Y: 54.8750  Z: 42.6875
X: 199.1875  Y: 47.3125  Z: 61.5625
X: 199.1250  Y: 42.1875  Z: 69.8750
X: 199.9375  Y: 39.1250  Z: 76.3125
X: 200.1875  Y: 38.8750  Z: 79.3125
X: 200.6250  Y: 39.8125  Z: 79.6875
X: 200.4375  Y: 40.5000  Z: 80.0000
X: 200.5000  Y: 40.8750  Z: 79.9375
X: 200.6875  Y: 41.1875  Z: 79.4375
X: 201.1875  Y: 42.0625  Z: 78.1875
X: 201.0625  Y: 42.9375  Z: 78.1875
X: 200.8750  Y: 44.0000  Z: 77.6250
X: 201.1875  Y: 47.6875  Z: 72.4375
X: 203.0000  Y: 54.3750  Z: 65.1250
X: 204.9375  Y: 61.5625  Z: 58.8125
X: 207.2500  Y: 68.8750  Z: 48.8750
X: 204.6875  Y: 74.3750  Z: 26.0000
X: 199.7500  Y: 78.0000  Z: 3.9375
X: 196.8125  Y: 81.1250  Z: -3.3125
X: 195.7500  Y: 83.0000  Z: -6.8125
X: 195.1875  Y: 84.5625  Z: -0.9375
X: 195.8125  Y: 84.3125  Z: -1.2500
X: 196.1875  Y: 83.8125  Z: -1.4375
X: 196.3750  Y: 83.5625  Z: -1.3750
X: 196.6250  Y: 83.0625  Z: -12.6250
X: 196.7500  Y: 82.6875  Z: -12.7500
X: 197.0625  Y: 82.1250  Z: -14.5000
X: 197.6875  Y: 81.8125  Z: -18.8125
X: 197.9375  Y: 81.5000  Z: -21.1250
X: 198.6875  Y: 81.4375  Z: -18.9375
X: 198.9375  Y: 80.2500  Z: -13.6875
X: 199.4375  Y: 76.6250  Z: -7.5625
X: 204.6250  Y: 72.3750  Z: 11.4375
X: 209.3125  Y: 66.5000  Z: 41.3750
X: 208.3125  Y: 58.5000  Z: 59.1250
X: 205.4375  Y: 49.7500  Z: 73.6250
X: 202.9375  Y: 43.1250  Z: 85.5625
X: 201.9375  Y: 38.5000  Z: 91.3750
X: 201.6250  Y: 37.1250  Z: 93.8750
X: 201.9375  Y: 38.1250  Z: 94.1875
X: 202.1875  Y: 38.9375  Z: 94.4375
X: 202.3125  Y: 39.3750  Z: 94.4375
X: 202.5625  Y: 39.6875  Z: 93.8750
X: 202.4375  Y: 40.0625  Z: 94.0000
X: 202.6875  Y: 40.5000  Z: 93.9375
X: 202.6250  Y: 40.5625  Z: 94.0625
X: 202.5000  Y: 40.9375  Z: 94.5625
X: 202.4375  Y: 41.8125  Z: 94.6250
X: 203.2500  Y: 44.9375  Z: 92.1875
X: 205.8125  Y: 51.3125  Z: 85.8750
X: 207.8750  Y: 57.8125  Z: 79.8125
X: 211.1250  Y: 65.6875  Z: 73.9375
X: 214.9375  Y: 73.3125  Z: 64.8125
X: 213.7500  Y: 78.1875  Z: 42.9375
X: 208.6875  Y: 80.5000  Z: 14.5000
X: 202.9375  Y: 82.6250  Z: 3.1875
X: 198.3750  Y: 83.4375  Z: -0.2500
X: 195.1875  Y: 84.1875  Z: -0.6250
X: 195.5000  Y: 84.5625  Z: -0.9375
X: 196.1875  Y: 84.0000  Z: -1.3125
X: 196.6875  Y: 83.6250  Z: -1.5000
X: 197.0625  Y: 83.2500  Z: -1.6875
X: 197.6250  Y: 82.8750  Z: -16.8125
X: 198.2500  Y: 82.3750  Z: -17.8750
X: 198.8750  Y: 82.0000  Z: -20.5000
X: 199.6250  Y: 81.4375  Z: -17.0625
X: 199.5000  Y: 79.8750  Z: -9.1875
X: 198.6250  Y: 77.1875  Z: 3.8750
X: 199.2500  Y: 72.1250  Z: 24.1250
X: 201.2500  Y: 65.9375  Z: 40.1250
X: 203.1875  Y: 59.3750  Z: 55.5625
X: 202.0000  Y: 51.9375  Z: 67.4375
X: 201.1875  Y: 45.8125  Z: 77.6875
X: 200.6250  Y: 41.6875  Z: 84.5625
X: 201.0625  Y: 39.1250  Z: 86.9375
X: 201.8750  Y: 40.0000  Z: 86.9375
X: 201.6250  Y: 40.6875  Z: 87.3125
X: 201.6875  Y: 41.1875  Z: 87.5000
X: 201.9375  Y: 41.5000  Z: 86.8125
X: 202.3125  Y: 42.0625  Z: 85.8750
X: 202.3125  Y: 42.0000  Z: 85.8750
X: 202.2500  Y: 42.1250  Z: 86.1250
X: 202.3125  Y: 42.2500  Z: 86.3125
X: 202.1875  Y: 42.5625  Z: 86.6250
X: 202.0000  Y: 43.5000  Z: 87.1875
X: 202.7500  Y: 45.8125  Z: 85.1875
X: 204.1875  Y: 50.1250  Z: 80.8125
X: 206.0625  Y: 57.2500  Z: 73.2500
X: 208.2500  Y: 63.6875  Z: 67.6250
X: 208.5625  Y: 70.1875  Z: 53.0625
X: 205.3750  Y: 75.5000  Z: 26.7500
X: 200.0625  Y: 78.1250  Z: 3.8125
X: 197.0625  Y: 81.0625  Z: -4.4375
X: 193.5000  Y: 83.6875  Z: -1.1875
X: 192.3750  Y: 85.3125  Z: -1.3125
X: 191.6875  Y: 85.3750  Z: -1.3750
X: 192.1250  Y: 84.7500  Z: -1.6250
X: 192.6875  Y: 84.1875  Z: -1.8750
X: 193.1875  Y: 83.6250  Z: -2.1250
X: 193.8750  Y: 82.6250  Z: -20.7500
X: 195.1875  Y: 82.2500  Z: -23.0625
X: 195.2500  Y: 82.1875  Z: -27.5000
X: 195.3125  Y: 82.1875  Z: -23.8125
X: 195.5000  Y: 80.5625  Z: -17.1250
X: 195.8750  Y: 77.3125  Z: -9.5625
X: 195.3125  Y: 73.1250  Z: 1.8125
X: 194.0625  Y: 67.3750  Z: 14.1875
X: 195.8750  Y: 62.6875  Z: 33.2500
X: 198.8750  Y: 57.1250  Z: 52.8750
X: 200.8750  Y: 50.5000  Z: 67.7500
X: 202.2500  Y: 44.8750  Z: 77.8750
X: 202.8750  Y: 41.0000  Z: 85.1250
X: 202.5625  Y: 38.2500  Z: 88.6875
X: 202.6250  Y: 38.1250  Z: 89.3750
X: 203.0000  Y: 39.6875  Z: 89.5000
X: 203.5000  Y: 41.0000  Z: 88.6250
X: 204.1875  Y: 41.8750  Z: 86.3750
X: 204.2500  Y: 42.0000  Z: 85.9375
X: 204.1250  Y: 42.3125  Z: 86.3750
X: 203.9375  Y: 42.8125  Z: 86.9375
X: 203.7500  Y: 43.5625  Z: 87.5625
X: 204.6250  Y: 46.5625  Z: 84.0625
X: 205.5625  Y: 51.1250  Z: 78.5625
X: 206.7500  Y: 56.1875  Z: 77.4375
X: 208.6250  Y: 62.4375  Z: 74.4375
X: 212.0625  Y: 69.5625  Z: 66.1250
X: 212.8750  Y: 75.3750  Z: 44.3125
X: 209.9375  Y: 78.5625  Z: 15.8750
X: 202.2500  Y: 79.8125  Z: -13.2500
X: 196.4375  Y: 81.3750  Z: -28.6875
X: 193.8125  Y: 83.5000  Z: -3.5625
X: 193.8750  Y: 83.6250  Z: -3.8125
X: 195.0625  Y: 82.4375  Z: -38.6875
X: 195.7500  Y: 81.8125  Z: -38.3125
X: 196.0000  Y: 81.5000  Z: -37.8125
X: 196.5000  Y: 81.0000  Z: -37.3125
X: 196.6875  Y: 80.8125  Z: -37.3750
X: 196.6875  Y: 80.8125  Z: -37.6250
X: 196.6875  Y: 80.5000  Z: -35.4375
X: 197.2500  Y: 79.3750  Z: -26.4375
X: 197.0000  Y: 76.3750  Z: -16.3750
X: 196.3750  Y: 72.1875  Z: -3.4375
X: 194.8750  Y: 67.6875  Z: 10.4375
X: 197.1875  Y: 63.5000  Z: 31.8125
X: 198.0000  Y: 57.6875  Z: 49.8125
X: 197.9375  Y: 50.6875  Z: 64.1875
X: 198.7500  Y: 45.8125  Z: 73.1875
X: 198.3750  Y: 42.2500  Z: 78.0000
X: 198.3750  Y: 38.5625  Z: 84.0625
X: 198.0625  Y: 37.1250  Z: 86.1875
X: 198.3750  Y: 37.7500  Z: 86.3750
X: 198.4375  Y: 38.5000  Z: 86.5625
X: 198.4375  Y: 38.9375  Z: 86.6875
X: 198.8125  Y: 39.3125  Z: 86.4375
X: 199.0625  Y: 40.0000  Z: 85.7500
X: 199.3125  Y: 41.0625  Z: 84.6250
X: 199.3125  Y: 41.5625  Z: 84.1875
X: 199.1250  Y: 43.0000  Z: 85.1250
X: 199.7500  Y: 46.5625  Z: 82.2500
X: 200.8125  Y: 51.8750  Z: 77.6250
X: 202.6250  Y: 58.3750  Z: 73.3750
X: 202.6875  Y: 65.5000  Z: 62.7500
X: 201.7500  Y: 70.3750  Z: 51.6875
X: 197.6875  Y: 74.1875  Z: 32.5000
X: 192.2500  Y: 76.3125  Z: 15.4375
X: 190.0625  Y: 78.7500  Z: 18.3750
X: 189.5625  Y: 79.9375  Z: 20.0625
X: 189.8750  Y: 80.3750  Z: 19.7500
X: 190.7500  Y: 80.1250  Z: 15.0625
X: 191.7500  Y: 79.7500  Z: 8.6875
X: 192.5625  Y: 79.0625  Z: 3.6875
X: 192.9375  Y: 78.2500  Z: 2.5000
X: 192.9375  Y: 77.8750  Z: 2.6875
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

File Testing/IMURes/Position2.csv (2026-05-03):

X: 0.0000  Y: 0.0000  Z: 0.0000
X: 0.0000  Y: 0.0000  Z: 0.0000
X: 0.0000  Y: 0.0000  Z: 0.0000
X: 0.0000  Y: 0.0000  Z: 0.0000
X: 0.0000  Y: 0.0000  Z: 0.0000
X: 0.0000  Y: 0.0000  Z: 0.0000
X: 0.0000  Y: 70.9375  Z: -65.8125
X: 0.0000  Y: 70.9375  Z: -65.8125
X: 0.0000  Y: 70.9375  Z: -65.8125
X: 0.0000  Y: 70.9375  Z: -65.8125
X: 0.0000  Y: 70.9375  Z: -65.8125
X: 0.0000  Y: 70.9375  Z: -65.8125
X: 0.0000  Y: 70.9375  Z: -65.8125
X: 0.0000  Y: 70.9375  Z: -65.8125
X: 0.0000  Y: 70.9375  Z: -65.8125
X: 0.0000  Y: 70.9375  Z: -65.8125
X: 0.0000  Y: 70.9375  Z: -65.8125
X: 0.0000  Y: 70.9375  Z: -65.8125
X: 359.8750  Y: 71.0625  Z: -65.9375
X: 0.1250  Y: 70.8125  Z: -65.8125
X: 0.0000  Y: 71.0000  Z: -66.0000
X: 359.8125  Y: 71.0000  Z: -65.5000
X: 358.7500  Y: 70.4375  Z: -62.5625
X: 346.3125  Y: 67.6875  Z: -61.8125
X: 337.6250  Y: 67.7500  Z: -46.4375
X: 325.9375  Y: 66.1250  Z: -23.4375
X: 316.3125  Y: 60.0000  Z: -10.0625
X: 310.8125  Y: 52.8125  Z: -4.7500
X: 308.5000  Y: 44.3750  Z: -3.8750
X: 310.5000  Y: 37.0625  Z: -1.1875
X: 311.0000  Y: 33.0000  Z: 3.2500
X: 310.7500  Y: 32.6250  Z: 4.5000
X: 310.1250  Y: 33.5000  Z: 6.0625
X: 309.3125  Y: 33.7500  Z: 6.3125
X: 309.3125  Y: 34.0000  Z: 6.0625
X: 309.5000  Y: 34.1250  Z: 5.9375
X: 309.1250  Y: 34.1250  Z: 6.1250
X: 308.7500  Y: 33.8750  Z: 5.0625
X: 309.1875  Y: 34.0625  Z: 5.9375
X: 309.2500  Y: 35.6875  Z: 4.4375
X: 319.3750  Y: 48.3750  Z: 28.3125
X: 340.3750  Y: 63.3750  Z: 47.2500
X: 353.5000  Y: 71.6250  Z: 41.9375
X: 9.0625  Y: 77.5625  Z: 34.8125
X: 19.6250  Y: 78.2500  Z: -2.5625
X: 23.9375  Y: 74.4375  Z: -27.0625
X: 215.3750  Y: 73.1250  Z: -35.3125
X: 215.1250  Y: 73.2500  Z: -34.3750
X: 214.5625  Y: 73.1875  Z: -32.8750
X: 214.3750  Y: 72.4375  Z: -31.9375
X: 214.8125  Y: 72.1875  Z: -31.0000
X: 214.9375  Y: 72.3750  Z: -31.0625
X: 214.5625  Y: 72.5625  Z: -31.1875
X: 214.0000  Y: 72.0000  Z: -30.9375
X: 213.8125  Y: 72.1250  Z: -30.8125
X: 213.5625  Y: 71.7500  Z: -29.0625
X: 212.8125  Y: 70.5000  Z: -25.2500
X: 202.3125  Y: 65.1250  Z: -27.2500
X: 193.5000  Y: 57.3750  Z: -27.8750
X: 186.0000  Y: 49.0000  Z: -25.8125
X: 177.6250  Y: 38.8750  Z: -25.5625
X: 173.3750  Y: 29.8125  Z: -24.8125
X: 168.7500  Y: 26.2500  Z: -23.3125
X: 165.3750  Y: 26.2500  Z: -19.0625
X: 164.3125  Y: 27.5000  Z: -17.8750
X: 164.2500  Y: 27.8125  Z: -18.0000
X: 164.0625  Y: 28.0000  Z: -17.9375
X: 164.0000  Y: 28.3750  Z: -18.0000
X: 163.8125  Y: 28.4375  Z: -18.1875
X: 163.6875  Y: 28.6250  Z: -18.2500
X: 163.8125  Y: 28.6250  Z: -18.4375
X: 163.9375  Y: 28.8125  Z: -18.3125
X: 163.8750  Y: 30.7500  Z: -17.0000
X: 169.1875  Y: 41.4375  Z: -1.3750
X: 177.3750  Y: 51.5625  Z: 12.2500
X: 185.1875  Y: 59.0625  Z: 14.0000
X: 198.0625  Y: 67.5625  Z: 13.2500
X: 207.8125  Y: 70.0000  Z: -4.6250
X: 214.6250  Y: 69.1250  Z: -22.6875
X: 218.9375  Y: 68.1875  Z: -36.2500
X: 219.4375  Y: 68.3125  Z: -37.4375
X: 219.1250  Y: 68.3125  Z: -35.8125
X: 219.4375  Y: 67.9375  Z: -34.5625
X: 219.6875  Y: 67.6250  Z: -34.0000
X: 219.7500  Y: 67.5625  Z: -33.9375
X: 219.3125  Y: 67.2500  Z: -34.8125
X: 219.5625  Y: 67.1875  Z: -35.1250
X: 219.4375  Y: 67.2500  Z: -35.3125
X: 218.6250  Y: 66.6875  Z: -33.1875
X: 215.0000  Y: 63.6875  Z: -23.3125
X: 202.6875  Y: 57.5000  Z: -23.3750
X: 190.6875  Y: 48.1875  Z: -23.5625
X: 179.1250  Y: 39.1250  Z: -25.1875
X: 172.4375  Y: 30.9375  Z: -26.1875
X: 167.5625  Y: 28.2500  Z: -22.3750
X: 165.4375  Y: 28.6250  Z: -15.4375
X: 165.6875  Y: 29.0000  Z: -15.6875
X: 165.7500  Y: 29.3125  Z: -15.9375
X: 165.5000  Y: 29.5000  Z: -16.0625
X: 165.5625  Y: 29.4375  Z: -16.2500
X: 165.7500  Y: 29.4375  Z: -16.5000
X: 165.5625  Y: 29.5625  Z: -16.5625
X: 165.3750  Y: 29.8125  Z: -16.6250
X: 165.3750  Y: 30.5625  Z: -16.4375
X: 165.1875  Y: 32.8750  Z: -20.5000
X: 170.6250  Y: 40.6250  Z: -11.2500
X: 175.8125  Y: 45.8125  Z: -9.6250
X: 181.5625  Y: 51.0625  Z: -10.3750
X: 186.6875  Y: 53.5000  Z: -20.3750
X: 192.5625  Y: 56.0000  Z: -29.0625
X: 198.0625  Y: 58.7500  Z: -34.1875
X: 201.7500  Y: 61.6250  Z: -37.1250
X: 202.6250  Y: 63.0000  Z: -40.5000
X: 202.3750  Y: 63.3125  Z: -40.5625
X: 202.2500  Y: 63.1875  Z: -40.1250
X: 202.1250  Y: 62.9375  Z: -39.5625
X: 201.9375  Y: 62.7500  Z: -39.2500
X: 201.8125  Y: 62.5625  Z: -38.9375
X: 201.6875  Y: 62.4375  Z: -38.9375
X: 201.6250  Y: 62.2500  Z: -38.8750
X: 201.6875  Y: 62.1250  Z: -38.6250
X: 201.6875  Y: 62.0625  Z: -38.6875
X: 200.5625  Y: 61.6250  Z: -38.7500
X: 199.8125  Y: 60.8125  Z: -37.0000
X: 197.8750  Y: 59.0625  Z: -34.7500
X: 193.7500  Y: 57.0000  Z: -32.0625
X: 187.8750  Y: 53.8125  Z: -31.9375
X: 183.1250  Y: 51.9375  Z: -30.0625
X: 178.5625  Y: 48.1875  Z: -30.8125
X: 174.2500  Y: 45.3125  Z: -29.6250
X: 170.6875  Y: 40.5000  Z: -30.6875
X: 167.8125  Y: 38.2500  Z: -27.0625
X: 165.3125  Y: 35.9375  Z: -25.3750
X: 164.3125  Y: 34.2500  Z: -24.1250
X: 164.5625  Y: 33.7500  Z: -21.6875
X: 163.3125  Y: 34.8750  Z: -21.1875
X: 162.6875  Y: 35.5000  Z: -21.0000
X: 162.4375  Y: 35.8125  Z: -20.9375
X: 162.3750  Y: 35.9375  Z: -21.0625
X: 162.5000  Y: 35.9375  Z: -21.2500
X: 162.4375  Y: 35.8750  Z: -21.3750
X: 162.5000  Y: 35.8750  Z: -21.4375
X: 162.6250  Y: 35.8750  Z: -21.5000
X: 162.8125  Y: 36.4375  Z: -21.2500
X: 162.8750  Y: 37.0000  Z: -22.6875
X: 165.4375  Y: 40.0625  Z: -21.1875
X: 169.2500  Y: 44.3750  Z: -18.3125
X: 174.1875  Y: 48.6875  Z: -14.3125
X: 179.0000  Y: 52.2500  Z: -13.5000
X: 182.6250  Y: 55.1875  Z: -15.5000
X: 185.0625  Y: 57.7500  Z: -19.7500
X: 187.6250  Y: 59.5000  Z: -24.3125
X: 190.6250  Y: 62.5000  Z: -26.0000
X: 194.4375  Y: 62.7500  Z: -31.6875
X: 198.9375  Y: 62.8750  Z: -37.9375
X: 200.4375  Y: 62.7500  Z: -42.8125
X: 200.8750  Y: 62.8125  Z: -43.6875
X: 200.3750  Y: 62.9375  Z: -43.3125
X: 200.3750  Y: 62.6250  Z: -42.9375
X: 200.3125  Y: 62.3750  Z: -42.6875
X: 200.1875  Y: 62.0625  Z: -42.1250
X: 199.9375  Y: 62.1875  Z: -41.8125
X: 199.7500  Y: 62.1250  Z: -41.5625
X: 199.6875  Y: 62.0625  Z: -41.4375
X: 199.7500  Y: 62.0625  Z: -41.3125
X: 199.5000  Y: 61.8750  Z: -40.6250
X: 199.0000  Y: 61.1875  Z: -39.4375
X: 197.3750  Y: 59.6250  Z: -36.5625
X: 196.0625  Y: 57.9375  Z: -32.1250
X: 193.5000  Y: 56.1875  Z: -26.2500
X: 188.8125  Y: 52.3750  Z: -24.4375
X: 184.3750  Y: 47.8125  Z: -27.1875
X: 180.9375  Y: 45.8750  Z: -26.9375
X: 177.1875  Y: 42.1875  Z: -29.5000
X: 174.1875  Y: 41.0000  Z: -27.6250
X: 171.2500  Y: 39.1250  Z: -27.5000
X: 167.9375  Y: 36.6250  Z: -28.9375
X: 166.8750  Y: 36.0625  Z: -26.1875
X: 166.8125  Y: 35.7500  Z: -24.1250
X: 166.5000  Y: 36.1250  Z: -23.8125
X: 166.1875  Y: 36.6250  Z: -23.9375
X: 165.8125  Y: 37.1250  Z: -23.8750
X: 165.4375  Y: 37.5000  Z: -23.9375
X: 165.4375  Y: 37.6250  Z: -24.1875
X: 165.4375  Y: 37.8125  Z: -24.2500
X: 165.4375  Y: 38.1875  Z: -24.0625
X: 165.3750  Y: 39.0625  Z: -24.2500
X: 166.1875  Y: 40.5625  Z: -24.4375
X: 168.6875  Y: 43.3750  Z: -22.6875
X: 172.8750  Y: 47.6250  Z: -19.4375
X: 178.1250  Y: 52.4375  Z: -18.0000
X: 182.8125  Y: 57.1250  Z: -17.1250
X: 187.1250  Y: 60.0000  Z: -20.8750
X: 192.1250  Y: 62.5000  Z: -24.8750
X: 198.7500  Y: 63.1875  Z: -31.6250
X: 202.0000  Y: 63.5000  Z: -38.7500
X: 203.4375  Y: 63.2500  Z: -43.9375
X: 203.4375  Y: 64.3125  Z: -45.8125
X: 203.1875  Y: 64.6250  Z: -46.8125
X: 202.9375  Y: 64.5625  Z: -46.7500
X: 202.6875  Y: 64.5000  Z: -46.6250
X: 202.6250  Y: 64.4375  Z: -46.9375
X: 202.6250  Y: 64.2500  Z: -47.3125
X: 202.5625  Y: 64.3125  Z: -47.5625
X: 202.5000  Y: 64.3750  Z: -47.8125
X: 202.5625  Y: 64.2500  Z: -48.0625
X: 202.6250  Y: 64.1250  Z: -47.8125
X: 202.5000  Y: 63.8750  Z: -47.2500
X: 201.8750  Y: 63.4375  Z: -46.8125
X: 200.8750  Y: 62.8125  Z: -45.3750
X: 199.7500  Y: 61.9375  Z: -41.8125
X: 198.3750  Y: 61.0000  Z: -36.6875
X: 196.4375  Y: 58.6250  Z: -29.0000
X: 189.3750  Y: 53.5625  Z: -30.6250
X: 184.1875  Y: 49.7500  Z: -30.8750
X: 179.3750  Y: 45.1250  Z: -32.5625
X: 175.4375  Y: 39.8750  Z: -35.0000
X: 173.7500  Y: 38.2500  Z: -33.5625
X: 173.0625  Y: 35.0000  Z: -34.6875
X: 172.7500  Y: 33.8750  Z: -34.5625
X: 172.6875  Y: 33.0625  Z: -34.9375
X: 172.7500  Y: 32.3125  Z: -35.1250
X: 172.3750  Y: 33.0625  Z: -35.2500
X: 172.1875  Y: 33.3750  Z: -35.4375
X: 172.1250  Y: 33.6250  Z: -35.5625
X: 172.0000  Y: 33.9375  Z: -35.6875
X: 171.8750  Y: 34.1250  Z: -35.8125
X: 172.0000  Y: 34.1875  Z: -35.9375
X: 172.0625  Y: 34.1875  Z: -36.0625
X: 171.8750  Y: 34.5000  Z: -36.1250
X: 171.6875  Y: 34.8125  Z: -36.3750
X: 171.4375  Y: 35.3125  Z: -36.5000
X: 171.0625  Y: 36.2500  Z: -36.5625
X: 170.6875  Y: 37.9375  Z: -36.6250
X: 170.5625  Y: 39.1875  Z: -37.8125
X: 173.7500  Y: 42.9375  Z: -34.8125
X: 176.9375  Y: 48.2500  Z: -31.0000
X: 180.2500  Y: 53.1250  Z: -30.0000
X: 184.5625  Y: 56.1875  Z: -32.6875
X: 191.3750  Y: 58.2500  Z: -35.3125
X: 197.4375  Y: 60.3125  Z: -38.0000
X: 201.2500  Y: 61.5625  Z: -41.5000
X: 202.3750  Y: 62.0625  Z: -46.7500
X: 202.3750  Y: 62.3125  Z: -47.5625
X: 202.3125  Y: 62.1875  Z: -47.6250
X: 202.3125  Y: 61.8750  Z: -47.3125
X: 202.1875  Y: 61.8750  Z: -47.1875
X: 202.0625  Y: 61.8125  Z: -46.9375
X: 201.8125  Y: 61.6875  Z: -46.5000
X: 201.6250  Y: 61.5625  Z: -45.9375
X: 201.5000  Y: 61.3125  Z: -45.3750
X: 201.2500  Y: 61.1875  Z: -44.8125
X: 200.8750  Y: 60.8125  Z: -43.4375
X: 199.1875  Y: 59.7500  Z: -41.3750
X: 197.7500  Y: 58.6250  Z: -36.5625
X: 193.7500  Y: 58.5000  Z: -33.6250
X: 188.3125  Y: 56.9375  Z: -33.6250
X: 183.8750  Y: 51.8125  Z: -37.2500
X: 181.1875  Y: 48.3750  Z: -39.8750
X: 177.8750  Y: 44.6875  Z: -43.6250
X: 174.7500  Y: 43.3750  Z: -43.8125
X: 172.8125  Y: 40.7500  Z: -42.1875
X: 171.4375  Y: 40.1250  Z: -40.3125
X: 170.4375  Y: 39.1250  Z: -39.9375
X: 168.6250  Y: 37.7500  Z: -39.0625
X: 168.1875  Y: 37.7500  Z: -35.5000
X: 167.7500  Y: 37.8125  Z: -34.7500
X: 167.4375  Y: 38.3125  Z: -35.1250
X: 167.1875  Y: 38.7500  Z: -35.3125
X: 166.8125  Y: 39.1250  Z: -35.1875
X: 166.5000  Y: 39.6250  Z: -35.1875
X: 166.6250  Y: 40.3125  Z: -34.9375
X: 166.4375  Y: 40.9375  Z: -35.2500
X: 166.2500  Y: 41.5625  Z: -35.0625
X: 165.6875  Y: 42.3750  Z: -35.6875
X: 167.6875  Y: 44.5000  Z: -32.7500
X: 170.8750  Y: 47.3750  Z: -29.4375
X: 174.8125  Y: 50.7500  Z: -25.4375
X: 179.3125  Y: 54.7500  Z: -20.6250
X: 182.5000  Y: 58.2500  Z: -17.6875
X: 184.7500  Y: 59.4375  Z: -20.1250
X: 187.1875  Y: 62.3750  Z: -18.6250
X: 189.1875  Y: 64.6250  Z: -19.0625
X: 191.7500  Y: 65.5625  Z: -22.0000
X: 194.7500  Y: 67.7500  Z: -24.3750
X: 195.8750  Y: 68.1875  Z: -30.7500
X: 196.6250  Y: 68.0625  Z: -34.1250
X: 196.5625  Y: 68.1250  Z: -33.9375
X: 196.3750  Y: 68.0000  Z: -33.3750
X: 196.3750  Y: 67.8125  Z: -33.1875
X: 196.5000  Y: 67.4375  Z: -32.8750
X: 196.3125  Y: 67.1250  Z: -32.0625
X: 196.1250  Y: 66.4375  Z: -30.9375
X: 196.0625  Y: 65.1875  Z: -29.8125
X: 194.5625  Y: 64.3125  Z: -29.1250
X: 193.9375  Y: 63.0625  Z: -27.0625
X: 190.2500  Y: 60.6875  Z: -30.6875
X: 187.2500  Y: 58.8750  Z: -31.3125
X: 184.2500  Y: 55.2500  Z: -32.5000
X: 182.1250  Y: 52.7500  Z: -33.3750
X: 180.7500  Y: 50.8750  Z: -33.6875
X: 177.9375  Y: 47.1250  Z: -37.5625
X: 175.8750  Y: 44.9375  Z: -39.7500
X: 174.4375  Y: 41.1875  Z: -42.3750
X: 174.3750  Y: 39.6250  Z: -43.4375
X: 173.5625  Y: 38.2500  Z: -45.5625
X: 173.5625  Y: 37.5000  Z: -46.2500
X: 173.1875  Y: 38.3750  Z: -46.3125
X: 172.9375  Y: 38.9375  Z: -46.3750
X: 172.8125  Y: 39.2500  Z: -46.3125
X: 172.6250  Y: 39.6875  Z: -46.3125
X: 172.5625  Y: 40.0625  Z: -46.3125
X: 172.5625  Y: 40.8750  Z: -46.0000
X: 172.5000  Y: 42.0625  Z: -45.6250
X: 171.9375  Y: 43.6250  Z: -45.5625
X: 171.1875  Y: 45.3750  Z: -45.5625
X: 170.5000  Y: 47.1250  Z: -45.5000
X: 172.6875  Y: 50.3125  Z: -42.1250
X: 176.2500  Y: 55.7500  Z: -37.1875
X: 178.5625  Y: 58.1875  Z: -37.5000
X: 182.1250  Y: 61.1250  Z: -37.0000
X: 186.3750  Y: 62.1875  Z: -39.1250
X: 191.1875  Y: 64.1250  Z: -40.4375
X: 192.9375  Y: 65.1875  Z: -42.8750
X: 193.1875  Y: 65.3750  Z: -44.0625
X: 192.8750  Y: 65.6250  Z: -43.6875
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

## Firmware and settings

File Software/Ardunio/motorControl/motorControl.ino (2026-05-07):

#include <Wire.h>
#include <Adafruit_PWMServoDriver.h>

Adafruit_PWMServoDriver pwm1 = Adafruit_PWMServoDriver(0x40);
Adafruit_PWMServoDriver pwm2 = Adafruit_PWMServoDriver(0x41);
Adafruit_PWMServoDriver* drivers[2] = {&pwm1, &pwm2};

const bool stepSequence[8][4] = {
  {1, 0, 0, 0}, {1, 0, 1, 0}, {0, 0, 1, 0}, {0, 1, 1, 0},
  {0, 1, 0, 0}, {0, 1, 0, 1}, {0, 0, 0, 1}, {1, 0, 0, 1}
};

// Defualt time values
const unsigned long TIMESTEP_MICROS = 100000;
const unsigned long MIN_SAFE_DELAY_MICROS = 2000; 

// PWM values
const int MOVE_POWER = 4000;
const int HOLD_POWER = 1228; /

// Motor Structure
struct StepperMotor {
  String name;
  uint8_t driverIndex;
  uint8_t baseChannel;
  float gearRatio;
  float stepAngle; 
  
  long currentPositionHalfSteps;
  long targetPositionHalfSteps; 
  
  int currentStepPhase;
  unsigned long lastStepTimeMicros; 
  unsigned long currentDelayMicros; 
  
  bool isMoving;
};

// motor setup
StepperMotor motors[7] = {
  // name, drv, chan, gear, stepAngle, currPos, targPos, phase, lastMicros, delayMicros, moving
  {"J1", 0, 0,  10.0, 0.225, 0, 0, 0, 0, 0, false}, 
  {"J2", 0, 4,  42.0, 0.225, 0, 0, 0, 0, 0, false}, 
  {"J3", 0, 8,  14.0, 0.225, 0, 0, 0, 0, 0, false}, 
  {"J4", 1, 12,  3.0, 0.900, 0, 0, 0, 0, 0, false}, 
  {"J5", 1, 8,   1.0, 0.900, 0, 0, 0, 0, 0, false}, 
  {"J6", 1, 4,   3.0, 0.900, 0, 0, 0, 0, 0, false}, 
  {"J7", 1, 0,   1.0, 0.900, 0, 0, 0, 0, 0, false}  
};

void setup() {

  Serial.begin(115200);
  Serial.setTimeout(10); 
  
  pwm1.begin();
  pwm1.setPWMFreq(1000); 
  pwm2.begin();
  pwm2.setPWMFreq(1000); 
  Wire.setClock(400000);
  delay(10);
  
  for (int i = 0; i < 7; i++) motorOff(motors[i]);

  Serial.println("System Ready");
}

void setLogicState(StepperMotor &motor, uint8_t channelOffset, bool isHigh) {
  uint8_t targetPin = motor.baseChannel + channelOffset;
  if (isHigh) {
    int currentPower = motor.isMoving ? MOVE_POWER : HOLD_POWER;
    drivers[motor.driverIndex]->setPWM(targetPin, 0, currentPower); 
  } else {
    drivers[motor.driverIndex]->setPWM(targetPin, 0, 4096); 
  }
}

void stepMotor(StepperMotor &motor, int dir) {
  motor.currentStepPhase += dir;
  if (motor.currentStepPhase > 7) motor.currentStepPhase = 0;
  if (motor.currentStepPhase < 0) motor.currentStepPhase = 7;

  setLogicState(motor, 0, stepSequence[motor.currentStepPhase][0]);
  setLogicState(motor, 1, stepSequence[motor.currentStepPhase][1]);
  setLogicState(motor, 2, stepSequence[motor.currentStepPhase][2]);
  setLogicState(motor, 3, stepSequence[motor.currentStepPhase][3]);
}

void motorOff(StepperMotor &motor) {
  setLogicState(motor, 0, false); setLogicState(motor, 1, false);
  setLogicState(motor, 2, false); setLogicState(motor, 3, false);
}


void parseAndExecutePositions(String input) {
  float targetAngles[7];
  int commaIndex;
  
 
  for (int i = 0; i < 6; i++) {
    commaIndex = input.indexOf(',');
    if (commaIndex == -1) return; 
    targetAngles[i] = input.substring(0, commaIndex).toFloat();
    input = input.substring(commaIndex + 1);
  }
  targetAngles[6] = input.toFloat(); 

 
  unsigned long moveStartTime = micros();
  
  for (int i = 0; i < 7; i++) {
    float baseHalfSteps = targetAngles[i] / motors[i].stepAngle;
    long newTarget = round(baseHalfSteps * motors[i].gearRatio);
    
    if (newTarget != motors[i].currentPositionHalfSteps) {
      motors[i].targetPositionHalfSteps = newTarget;
      
      long stepsRequired = abs(motors[i].targetPositionHalfSteps - motors[i].currentPositionHalfSteps);
      
      
      motors[i].currentDelayMicros = TIMESTEP_MICROS / stepsRequired;
      
      
      if (motors[i].currentDelayMicros < MIN_SAFE_DELAY_MICROS) {
         motors[i].currentDelayMicros = MIN_SAFE_DELAY_MICROS;
      }
      
      motors[i].isMoving = true;
      motors[i].lastStepTimeMicros = moveStartTime; 
      
      stepMotor(motors[i], 0); 
    } else if (motors[i].isMoving) {

      motors[i].isMoving = false;
      stepMotor(motors[i], 0); 
    }
  }
}


void updateAllMotors() {
  unsigned long currentMicros = micros();

  for (int i = 0; i < 7; i++) {
    if (motors[i].isMoving) {
      long stepsRemaining = motors[i].targetPositionHalfSteps - motors[i].currentPositionHalfSteps;
      
      if (stepsRemaining != 0) {
        if (currentMicros - motors[i].lastStepTimeMicros >= motors[i].currentDelayMicros) {
          
          int dir = (stepsRemaining > 0) ? 1 : -1;
          stepMotor(motors[i], dir);
          
          motors[i].currentPositionHalfSteps += dir;
          
          
          motors[i].lastStepTimeMicros += motors[i].currentDelayMicros; 
        }
      } 
      else {

        motors[i].isMoving = false; 
        stepMotor(motors[i], 0); 
      }
    }
  }
}

void loop() {
  updateAllMotors(); 
  // Check for incoming trajectories
  if (Serial.available() > 0) {
    String input = Serial.readStringUntil('\n');
    input.trim(); 
    if (input.length() > 0) {
      parseAndExecutePositions(input);
    }
  }
}

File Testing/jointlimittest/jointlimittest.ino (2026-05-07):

#include <Wire.h>
#include <Adafruit_PWMServoDriver.h>

Adafruit_PWMServoDriver pwm1 = Adafruit_PWMServoDriver(0x40);
Adafruit_PWMServoDriver pwm2 = Adafruit_PWMServoDriver(0x41);
Adafruit_PWMServoDriver* drivers[2] = {&pwm1, &pwm2};

const bool stepSequence[8][4] = {
  {1, 0, 0, 0}, {1, 0, 1, 0}, {0, 0, 1, 0}, {0, 1, 1, 0},
  {0, 1, 0, 0}, {0, 1, 0, 1}, {0, 0, 0, 1}, {1, 0, 0, 1}
};

g
const unsigned long MIN_DELAY_MICROS = 15000;  
const unsigned long MAX_DELAY_MICROS = 60000; 
const long MAX_ACCEL_STEPS = 400;             


const int MOVE_POWER = 4000; 
const int HOLD_POWER = 1228;


struct StepperMotor {
  String name;
  uint8_t driverIndex;
  uint8_t baseChannel;
  float gearRatio;
  float stepAngle; 
  
  long currentPositionHalfSteps;
  long targetPositionHalfSteps; 
  unsigned long totalStepsMoved; 
  

  long startPositionHalfSteps; 
  long accelSteps;             
  
  int currentStepPhase;
  unsigned long lastStepTimeMicros; 
  unsigned long currentDelayMicros; 
  
  bool isMoving;
};

StepperMotor motors[7] = {
  // name, drv, chan, gear, stepAngle, currPos, targPos, totalSteps, startPos, accelStp, phase, lastMicros, currMicros, moving
  {"J1", 0, 0,  10.0, 0.225, 0, 0, 0, 0, 0, 0, 0, 0, false}, // 4x smaller step size
  {"J2", 0, 4,  42.0, 0.225, 0, 0, 0, 0, 0, 0, 0, 0, false}, // 4x smaller step size
  {"J3", 0, 8,  14.0, 0.225, 0, 0, 0, 0, 0, 0, 0, 0, false}, // 4x smaller step size
  {"J4", 1, 12,  3.0, 0.900, 0, 0, 0, 0, 0, 0, 0, 0, false}, // Standard step size
  {"J5", 1, 8,   1.0, 0.900, 0, 0, 0, 0, 0, 0, 0, 0, false}, 
  {"J6", 1, 4,   3.0, 0.900, 0, 0, 0, 0, 0, 0, 0, 0, false}, 
  {"J7", 1, 0,   1.0, 0.900, 0, 0, 0, 0, 0, 0, 0, 0, false}  
};

enum InputState { WAITING_FOR_MOTOR, WAITING_FOR_ANGLE };
InputState currentState = WAITING_FOR_MOTOR;
int selectedMotorIndex = -1; 

void setup() {
 
  Serial.setTimeout(50); 
  
  Serial.println("--- 7-Axis Stepper Control (Accel, Microstep & Holding Fixes) ---");

  pwm1.begin();
  pwm1.setPWMFreq(1000); 
  pwm2.begin();
  pwm2.setPWMFreq(1000); 
  Wire.setClock(400000);
  delay(10);
  
  for (int i = 0; i < 7; i++) motorOff(motors[i]);

  Serial.println("System Ready.");
  Serial.println("\nWhich motor? (1-7):");
}

void setLogicState(StepperMotor &motor, uint8_t channelOffset, bool isHigh) {
  uint8_t targetPin = motor.baseChannel + channelOffset;
  if (isHigh) {
    int currentPower = motor.isMoving ? MOVE_POWER : HOLD_POWER;
    drivers[motor.driverIndex]->setPWM(targetPin, 0, currentPower); 
  } else {
    drivers[motor.driverIndex]->setPWM(targetPin, 0, 4096); 
  }
}

void stepMotor(StepperMotor &motor, int dir) {
  motor.currentStepPhase += dir;
  if (motor.currentStepPhase > 7) motor.currentStepPhase = 0;
  if (motor.currentStepPhase < 0) motor.currentStepPhase = 7;

  setLogicState(motor, 0, stepSequence[motor.currentStepPhase][0]);
  setLogicState(motor, 1, stepSequence[motor.currentStepPhase][1]);
  setLogicState(motor, 2, stepSequence[motor.currentStepPhase][2]);
  setLogicState(motor, 3, stepSequence[motor.currentStepPhase][3]);
}

void motorOff(StepperMotor &motor) {
  setLogicState(motor, 0, false); setLogicState(motor, 1, false);
  setLogicState(motor, 2, false); setLogicState(motor, 3, false);
}

void releaseOtherMotors(StepperMotor &activeMotor) {
  for (int i = 0; i < 7; i++) {
    if (&motors[i] != &activeMotor && !motors[i].isMoving) {
      motorOff(motors[i]);
    }
  }
}


void setTargetAngle(StepperMotor &motor, float targetAngle) {
  float baseHalfSteps = targetAngle / motor.stepAngle;
  long newTarget = round(baseHalfSteps * motor.gearRatio);
  
  if (newTarget != motor.currentPositionHalfSteps) {
    
    releaseOtherMotors(motor);
    
    /
    motor.startPositionHalfSteps = motor.currentPositionHalfSteps;
    motor.targetPositionHalfSteps = newTarget;
    
    
    long totalSteps = abs(motor.targetPositionHalfSteps - motor.startPositionHalfSteps);
    motor.accelSteps = totalSteps / 3; 
    if (motor.accelSteps > MAX_ACCEL_STEPS) motor.accelSteps = MAX_ACCEL_STEPS;
    
    motor.isMoving = true;
    motor.currentDelayMicros = MAX_DELAY_MICROS; 
    motor.lastStepTimeMicros = micros();
    
    stepMotor(motor, 0); 
    
    Serial.print(motor.name);
    Serial.print(" target set to ");
    Serial.println(targetAngle);
  } else {
    Serial.println("Already at target. Holding torque maintained.");
  }
}


void updateAllMotors() {
  unsigned long currentMicros = micros();

  for (int i = 0; i < 7; i++) {
    long stepsRemaining = motors[i].targetPositionHalfSteps - motors[i].currentPositionHalfSteps;
    
    if (stepsRemaining != 0) {
      
      if (currentMicros - motors[i].lastStepTimeMicros >= motors[i].currentDelayMicros) {
        
        int dir = (stepsRemaining > 0) ? 1 : -1;
        stepMotor(motors[i], dir);
        
        motors[i].currentPositionHalfSteps += dir;
        motors[i].totalStepsMoved++; // 
        motors[i].lastStepTimeMicros = currentMicros; 
        
        /
        long stepsMoved = abs(motors[i].currentPositionHalfSteps - motors[i].startPositionHalfSteps);
        long absRemaining = abs(motors[i].targetPositionHalfSteps - motors[i].currentPositionHalfSteps);
        
        if (stepsMoved < motors[i].accelSteps) {
          
          float progress = (float)stepsMoved / motors[i].accelSteps;
          motors[i].currentDelayMicros = MAX_DELAY_MICROS - (progress * (MAX_DELAY_MICROS - MIN_DELAY_MICROS));
        } 
        else if (absRemaining < motors[i].accelSteps) {
          
          float progress = (float)absRemaining / motors[i].accelSteps;
          motors[i].currentDelayMicros = MAX_DELAY_MICROS - (progress * (MAX_DELAY_MICROS - MIN_DELAY_MICROS));
        } 
        else {
          
          motors[i].currentDelayMicros = MIN_DELAY_MICROS;
        }
      }
    } 
    else if (motors[i].isMoving) {
      motors[i].isMoving = false; 
      
     
      
      stepMotor(motors[i], 0); 
      releaseOtherMotors(motors[i]);
      
      Serial.print("\n>>> "); Serial.print(motors[i].name);
      Serial.println(" arrived and holding position.");
      
    
      Serial.print(">>> Total steps moved so far (Odometer): ");
      Serial.println(motors[i].totalStepsMoved);
      
      Serial.println("Which motor next? (1-7):");
    }
  }
}
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

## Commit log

2026-05-03 Add all previous code
    [ClampingHub.stl, ElectronicsBox.stl, ElectronicsBox2.stl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]
2026-05-03 Add Simulator and BOM
    [BEATRIX BOM.xlsx]
2026-05-03 add schem
    [schemBEATRIX.SchDoc]
